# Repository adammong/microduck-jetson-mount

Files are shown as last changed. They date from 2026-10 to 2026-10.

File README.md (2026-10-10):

# MicroDuck Jetson Orin Nano mount

Parametric CAD, printable parts, assembled previews and MuJoCo models for an external MicroDuck compute mount. Current design: **v06**, with the Jetson low in front, ports upward, and a **GNB8504S60AHV 4S LiHV 850 mAh battery** behind the torso to balance it.

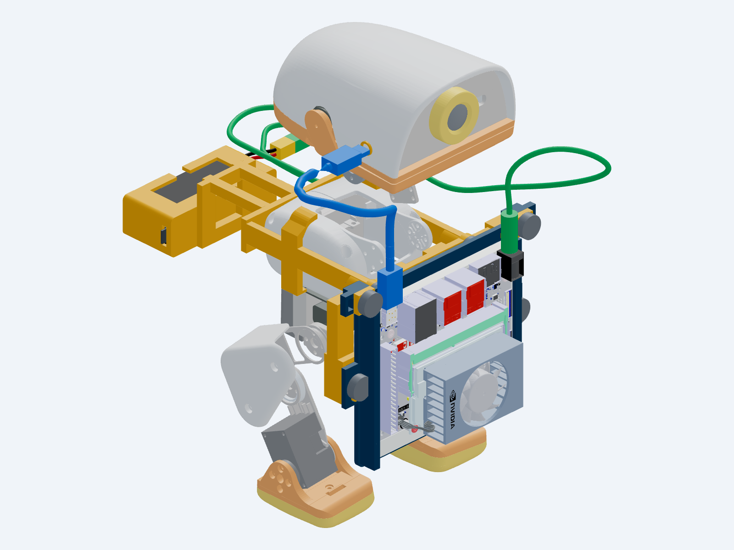
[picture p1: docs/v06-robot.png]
MicroDuck with the balanced v06 mount


## Directional control

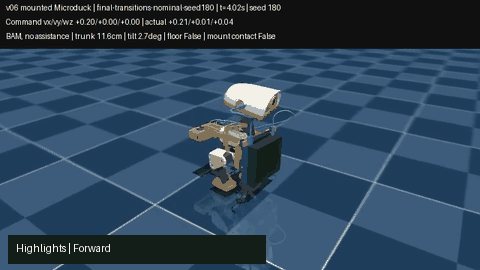
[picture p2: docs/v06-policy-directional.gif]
Directional-control highlights


The new **Mac-calibrated directional policy** supports forward/backward, sidesteps, turns, diagonals and curves. It passed **176/176 fresh 30-second simulation trials** with the v06 payload, including observation noise and randomized physics, plus **8/8 complete 69-second control sequences**, with no detected mount contacts. Direction tracking is checked separately from staying upright. Forward/backward presets are +0.20/-0.15 m/s, sideways ±0.10 m/s and turns ±0.40 rad/s. Low-speed commands can still hit the inherited dead zone; hardware is untested.

**Try it on the Mac:** after [setup](training/README.md), run `OMP_NUM_THREADS=1 tmp/microduck-lab/microduck_local/.venv/bin/python training/teleop_motion.py`, then open http://127.0.0.1:8798. Hold **W/S** forward/back, **A/D** sideways, **Q/E** turn; **Space** stops. Movement and turn keys combine into curves. The control page includes command ramps, stale-command stopping and reset.

[Full directional video](https://github.com/adammong/microduck-jetson-mount/raw/refs/heads/main/results/motion-v06/motion-demo.mp4) · [Selected ONNX](results/motion-v06/policies/selected/policy.onnx) · [Measurements, training and limitations](results/motion-v06/REPORT.md).

## Faster walking video

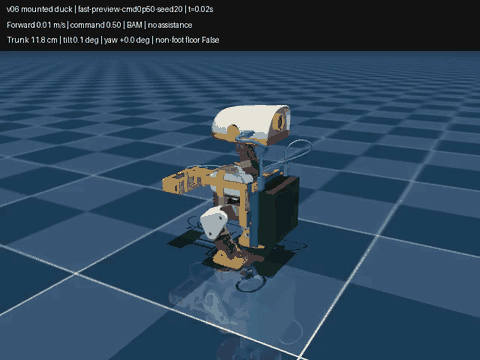
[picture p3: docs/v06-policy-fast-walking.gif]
Faster walking policy on the loaded v06 robot


**New Mac-trained fast-walking policy:** about **0.27 m/s**, roughly **59% faster** than the original policy's successful normal walks. It survived **16/16 fresh 30-second trials**, including observation noise and randomized physics, with no detected mount contacts. Four start/stop sequences also survived. The selected policy retains the original walking network and adds small trained gyro/gravity corrections; both PPO fine-tunes remain rejected.

[Watch the fast-walking MP4](https://github.com/adammong/microduck-jetson-mount/raw/refs/heads/main/results/speed-v06/fast-walking.mp4) · [Selected ONNX policy](results/speed-v06/policies/selected/policy.onnx) · [Measurements, limits and reproduction](results/speed-v06/REPORT.md). Tested forward command: `[0.5, 0, 0]`. This is fast walking in simulation; hardware performance and higher-speed running remain unverified.

Original policy comparison:

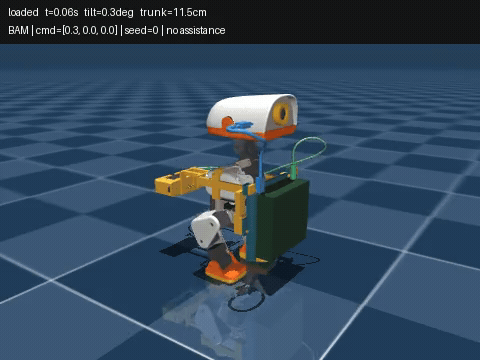
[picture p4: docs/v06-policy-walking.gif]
Walking policy on the loaded v06 robot


[Watch or download the full MP4](https://github.com/adammong/microduck-jetson-mount/raw/refs/heads/main/results/mac-v06/preview-loaded-forward.mp4). This is the unchanged official walking policy on the loaded v06 model in Mac MuJoCo simulation, with no assistance; it is not a hardware demonstration. The earlier PPO fine-tunes remain rejected.

## Start here

- [Assembly, hardware, printing and limitations](easy_mount/README.md)
- [Wiring and compute-board access](easy_mount/WIRING.md)
- [Battery selection and runtime assumptions](easy_mount/battery_selection.json)
- [Complete robot preview](easy_mount/GLB/microduck_easy_mount_v06.glb)
- [Editable CAD assembly](easy_mount/STEP/easy_mount_assembly.step)
- [Five print STLs](easy_mount/STL/)
- [MuJoCo models and validation reports](easy_mount/simulation/)
- [Mac simulation and training](training/README.md) · [Faster walking results](results/speed-v06/REPORT.md) · [v06 simulation findings](results/mac-v06/REPORT.md) · [historical v05 findings](results/mac-v05/REPORT.md)

The estimated payload is **442.1 g**, including **120.1 g** fully dense PETG and estimated ancillary hardware. The battery is specified at **73 g**, with **12.92 Wh** nominal energy. Runtime arithmetic estimates 22–37 minutes at 15–25 W total Jetson draw, including reserve and conversion losses; it does not predict robot motor runtime.

## Prototype status

Physical shell fit, structural strength, power conditioning/protection and hardware walking are unverified. The directional policy now follows the measured motion presets in the loaded simulation; arbitrary slow speeds remain ineffective. The original teacher and rejected candidates remain available for comparison. Full joint travel has recorded collisions. The blue USB cable ends at a free, unverified head-side plug; the amber ring is a survey marker, not a stock port. Approximate purchased leads/connectors are illustrated. The larger 1100 mAh pack was researched but has **not** been integrated into this CAD.

## Rebuild

Use Python 3.12. From the repository root:

```sh
python3.12 -m venv .venv
.venv/bin/python -m pip install -r requirements.txt
sh easy_mount/build.sh
.venv/bin/python checks/package_easy_mount.py
```

Only print the five files in `easy_mount/STL/`. Electronics, battery, wires, knobs and straps are purchased components. CAD dimensions are millimeters; MuJoCo uses meters and kilograms.

See [third-party attribution](THIRD_PARTY.md). Upstream robot assets and NVIDIA geometry retain their respective terms.

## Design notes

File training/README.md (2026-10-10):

# Local Mac simulation and training

Uses [MicroDuck Lab](https://github.com/jonathanhawkins/microduck-lab/tree/bbf0326ef97975f7062368914e0729504d17226f), pinned to `bbf0326ef97975f7062368914e0729504d17226f`. Native CPU MuJoCo and PPO work on Apple Silicon; CUDA is unnecessary for these experiments.

The current CAD revision is the source of payload mass, inertia and collision boxes. Stock and loaded scenes share the robot, floor, STAND keyframe, BAM XL330 motor model, 200 Hz physics and 50 Hz policy interface: **61 observations / 14 actions**. Both use the fuller groundcontact robot. The Jetson visual is an envelope; cables are fixed and the mount cannot slip or break in this model.

## Run

From the repository root, with [uv](https://docs.astral.sh/uv/getting-started/installation/) installed:

```sh
uv run --python 3.12 training/setup_mac.py
tmp/microduck-lab/microduck_local/.venv/bin/python training/verify.py
tmp/microduck-lab/microduck_local/.venv/bin/python training/evaluate.py --strict --seeds 8 --seconds 20 --render
tmp/microduck-lab/microduck_local/.venv/bin/python training/evaluate.py --variant loaded --strict --extended --bus-delay --obs-noise
```

Outputs use the revision in `easy_mount/parameters.json`: current metrics/videos go into `results/mac-v06/`, and compiled scenes into `tmp/mac-models/v06/`. `--revision v05` evaluates preserved local v05 scenes if present; a fresh checkout must build those from the historical CAD revision first. Existing historical results are committed in `results/mac-v05/`.

## Exact teacher import and bounded fine-tuning

The official ONNX actor can now be copied exactly into a resumable PPO checkpoint. Its normalizer and ELU layers are retained; only the initial critic is fitted to mounted rollouts. Equality is asserted before and after critic fitting. This avoids approximate actor cloning and preserves normalized command slots during later warm starts.

```sh
tmp/microduck-lab/microduck_local/.venv/bin/python training/import_teacher.py --episodes 80 --critic-epochs 20
tmp/microduck-lab/microduck_local/.venv/bin/python training/train_pair.py --variant loaded --steps 262144 --init-from tmp/mac-runs/v06-teacher-import-s0 --lr 0.00001 --run-tag teacher
tmp/microduck-lab/microduck_local/.venv/bin/python training/verify_teacher.py --warm-run tmp/mac-runs/v06-loaded-bam-s0-262144-strict-warm-teacher
```

The training driver runs bounded paired numerical studies with eight workers, CPU PPO and a strict floor-support guard. It uses nominal mass and no observation noise; BAM still samples startup voltage/sag and uses bus delay. This is not the full hardware-transfer recipe. Use the upstream live LAB for general skill training. Logs, checkpoints and exports are stored in `tmp/mac-runs/`. `--seed`, `--run-tag`, `--lr` and `--init-from` control repeat studies. Existing outputs are preserved; choose a fresh run tag to repeat. Archived checkpoints use `model.sb3`; the driver restores this native ZIP container to temporary `model.zip` before loading it.

The guard ends an episode after three successive control steps with a non-foot floor contact carrying more than 0.05 N. Observations, actions, rewards and motor limits remain intact. `--allow-nonfoot-support` exists only to reproduce the historical backpack-supported failure. Evaluation defaults to nominal physics, with optional communication delay, observation noise and domain randomization. Trials load isolated model copies and seed both construction and reset.

## Results and selection

The [directional-motion study](../results/motion-v06/REPORT.md) adds a simulation controller for forward/backward, both sidesteps, both turns, diagonals and curves, plus a keyboard/button page. Six command-conditioned maps and bounded gyro/gravity corrections retain the teacher's exact neural weights and normalization. Paired CEM studies also calibrate turn startup from settled standing and a gyro-based start boost. Final checks use the same command slew as the page: 176/176 fresh 30-second nominal/randomized trials and 8/8 full 69-second sequences, with separate direction-tracking checks and no detected mount contact. Low-command dead zones and hardware transfer remain unresolved.

```sh
OMP_NUM_THREADS=1 tmp/microduck-lab/microduck_local/.venv/bin/python training/teleop_motion.py
OMP_NUM_THREADS=1 tmp/microduck-lab/microduck_local/.venv/bin/python training/verify_motion.py
OMP_NUM_THREADS=1 tmp/microduck-lab/microduck_local/.venv/bin/python training/evaluate_motion_batch.py --policy results/motion-v06/policies/selected/policy.onnx --out tmp/directional.json --seeds 8 --seed-start 200 --seconds 30 --slew
```

Open http://127.0.0.1:8798. W/S forward/back, A/D sideways, Q/E turn, Space stop. Body-frame presets are +0.20/-0.15 m/s forward/back, ±0.10 m/s sideways and ±0.40 rad/s yaw; movement/turn keys combine. The controller requires its tested command ramp and 0.6-second stale-input watchdog. It exports one 61-input/14-output ONNX; CEM parameters and all searches are retained. This is a bounded numerical calibration study, rather than another PPO fine-tune. Earlier candidates, cold-start failures and missed turns remain in the report.

The [faster-walking study](../results/speed-v06/REPORT.md) selects a **simulation-only** feedback correction policy for forward command `[0.5, 0, 0]`. It averages 0.266 m/s net forward progress, with 16/16 fresh 30-second nominal/randomized trials surviving without detected mount contacts. The original teacher network and normalization are retained; bounded gyro/gravity corrections are trained with CEM. Normal/idle commands at or below 0.35 retain the original teacher's output exactly. The study records the rejected 2M/3M-step LAB PPO attempts and the complete bounded calibration history.

```sh
OMP_NUM_THREADS=1 VECLIB_MAXIMUM_THREADS=1 tmp/microduck-lab/microduck_local/.venv/bin/python training/tune_fast_feedback.py --out tmp/repeat-fast-feedback --generations 8 --population 20 --command .5 --seconds 25 --training-seeds 0 1 2 3 4 5 6 7 8 9 10 11
OMP_NUM_THREADS=1 tmp/microduck-lab/microduck_local/.venv/bin/python training/evaluate_speed.py --policy results/speed-v06/policies/selected/policy.onnx --out tmp/recheck-fast.json --commands .5 --seeds 8 --seed-start 20 --seconds 30 --render
```

The selected graph still uses 61 observations / 14 actions at 50 Hz. It is an ONNX policy, with parameters and provenance under `results/speed-v06/policies/selected/`; it is not a resumable PPO checkpoint. CEM resumes conceptually from its recorded parameters/search, and PPO comparison checkpoints remain separately archived. Published measurements validate the 0.5 forward operating point, not higher speeds or general turning. See the report for sampling limits and hardware gaps.

[The v06 report](../results/mac-v06/REPORT.md) shows a substantial **mount balance improvement** with the unchanged walking teacher. The teacher remains the preferred comparison actor: both fine-tuning attempts failed to beat it reliably. Their checkpoints are marked rejected. Surviving a reverse, lateral or turn-in-place trial does not mean following its command; these motions remain ineffective. Randomized forward/curved trials still expose falls and occasional mount contacts.

The [v05 pilots](../results/mac-v05/REPORT.md) are also rejected. Retained artifacts support reproducibility, not deployment. Printed mass, motor heating, shell strength and real fit remain unverified. Inputs and checksums are in [inputs.json](inputs.json); scene source hashes in [scenes.json](../results/mac-v06/scenes.json). The pinned harness's `uv.lock` fixes training dependencies; CAD dependencies remain separate.

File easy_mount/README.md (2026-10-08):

# External captive Jetson mount — v06 fit prototype

The Jetson Orin Nano developer kit sits **low in front**, with USB/Ethernet/DC ports upward. The GNB 4S 850 mAh battery sits **behind the torso**, counterbalancing the Jetson. Two independent corner retainers replace the head-interfering crossbar. Tray windows reduce plastic mass. The external torso capture remains; mounting does not require opening the torso or removing its screws.

## Attach the mount and Jetson

1. Prepare the five prints below, insert six M4 nuts, and fit nonconductive foam: nominally 1 mm at the upper saddle seats and 2 mm at the torso gate pads. Clear supports and tune nut-pocket clearance to the printer.
2. Support the powered-off duck. Remove the yellow front torso gate. Slide the saddle forward onto the torso from behind: upper seats rest on the shell shoulders; lower lips capture its side undersides. Refit the gate with **two M4×20 thumb screws**, seated gently.
3. On the bench, remove the tray's **two small corner retainers**. Keep NVIDIA's white plastic base attached. Orient its connector edge upward and slide the base down between the rails to the lower stops. Refit the retainers with **two M4×12 thumb screws**. These retain the plastic base; no PCB holes are used.
4. Engage the tray's locating holes on the front gate's outboard pins. Secure **two M4×20 thumb screws**. Removing these two screws releases the equipped tray later.
5. Place the battery on the 0.6 mm bottom pad in the rear pocket, then strap it through the pocket slots. Its leads leave through the short-edge notch. Strap a verified power-conditioning/protection device to the rear side pad. Restrain wiring with slack at moving joints.

These are intended operations, not a physically demonstrated installation. Production shell fit, pad compression and fastener access need a fit print. Connecting the duck's compute board may require separate head access. The amber ring is a survey marker, **not a stock port**; the blue head-end plug is deliberately disconnected. See [WIRING.md](WIRING.md).

## Parts and printing

Print only these five files:

- `STL/saddle.stl`
- `STL/front_gate.stl`
- `STL/jetson_tray.stl`
- `STL/jetson_gate_left.stl`
- `STL/jetson_gate_right.stl`

Hardware: four M4×20 and two M4×12 thumb screws; six ISO 4032 M4 nuts; nonconductive pads and retaining straps. Electronics, cables, battery, converter and gray knobs are purchased-component illustrations.

Screw holes are 4.5 mm; nut pockets are 7.25 mm across flats and 3.5 mm deep. The OEM base is nominally 103×90.5 mm. The rail internal width is 104.2 mm, with 0.8 mm lip overlap and nominal 0.5 mm clearance above the base. PETG is the mass assumption; capture seats, rail lips, ears and nut pockets still require support and strength review. All print STLs are watertight, with their bottom at Z=0. No slicer or strength certification is implied.

Battery: **GNB8504S60AHV**, 73×18×32 mm, 73 g ±2 g, 15.2 V, 850 mAh, 12.92 Wh. Body center `[-122.6,0,0]` mm in trunk coordinates. Pocket interior 75×20 mm, 36 mm deep. End straps occupy the nominal 1 mm end clearance; tune their thickness to the actual pack. Factory lead placement and XT30/balance connectors are approximate. The converter remains an **unselected** 14×24×12 mm allowance.

## CAD and simulation

- [Complete robot preview](GLB/microduck_easy_mount_v06.glb)
- [Equipped mount](GLB/equipped_mount_v06.glb)
- [Head wiring inspection](GLB/head_wiring_inspection_v06.glb): older reference PCB footprint, with the cover omitted; production Radxa socket geometry is unverified.
- [Editable assembly](STEP/easy_mount_assembly.step), plus five individual print STEP files.
- `simulation/microduck_easy_mount_{walk,groundcontact}.xml`: both baseline robot variants, with explicit payload inertia, zero-mass visuals and active rigid mount collision boxes.
- `simulation/{mass_properties,validation,balance_estimate}.json`: generated numerical results.
- [Mac simulation report](../results/mac-v06/REPORT.md).

CAD units are millimeters; simulation uses meters and kilograms. Trunk X is forward, Y left, Z up. Tray local `(X,Y,Z)` maps to trunk `(Z,X,Y)` plus `[50,0,-18]` mm; the vendor kit rotates 180° around tray Z first. `parameters.json` controls positions, dimensions and mass assumptions.

Payload mass is **442.1 g**: **120.1 g** fully dense PETG, Jetson 175 g, battery 73 g, and 74 g ancillary allowance (fasteners/pads/straps 22 g, data cable 14 g, power wiring/extension 18 g, conditioning/protection 20 g). The payload is counted once; the stock robot battery remains. Weigh sliced prints and purchased hardware before calibrating inertia. Cable mass is fixed in HOME; head articulation and cable tension are not modeled.

## Verification and limits

Five valid single print solids and five watertight STLs pass native print/print, battery/strap/factory-lead/print and wire/print intersection checks. The 50 mm upward plug corridor clears prints and the sampled robot poses. HOME plus 126 individual-joint samples within ±0.2 rad has no reported penetration beyond 0.2 mm. **Full-range motion still records 140 interfering pairs**; this design does not clear the complete stock motion range or combined head/leg motions.

Static HOME COM shifts **2.1 mm forward, 1.5 mm left and 9.0 mm down**. Optimistic rear sole margin is **22.7 mm**, versus 8.5 mm in v05 and 20.5 mm stock. This assumes usable contact over the entire projected sole; it is not a payload rating. Paired walking rollouts support the balance improvement, but hardware strength, fit, motor temperature and power remain unverified.

## Battery and power

[Manufacturer specification](https://www.gaoneng.shop/products/gaoneng-gnb-lihv-4s-15.2v-850mah-60c-xt30-lipo-battery-long-range) and [selection record](battery_selection.json) document the pack. No exact battery CAD was available: its body uses published dimensions, with illustrative leads and connectors.

At 15–25 W total Jetson draw, 80% usable energy and 90% conditioning efficiency imply **22–37 minutes**. This does not predict robot motor runtime. Full-charge 17.4 V is within NVIDIA's published 9–20 V carrier input range, but protection, transients, cutoff and the actual circuit are unvalidated. Use suitable LiHV charging equipment and verify actual lead exit, plugs and power hardware before fitting.

## Rebuild

From the repository root, using the Python 3.12 CAD environment:

```sh
sh easy_mount/build.sh
.venv/bin/python checks/package_easy_mount.py
```

`CAD_PYTHON` can select an existing CAD interpreter. Model sources are in `src/`, shared geometry in `src/lib/`, checks in `checks/`. The packaging command creates a versioned ZIP under `dist/` containing the current design and pinned rebuild inputs. See [third-party attribution](../THIRD_PARTY.md); robot and NVIDIA assets retain their respective terms.

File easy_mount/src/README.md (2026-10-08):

# Model catalog

Four scripts build print parts with STEP/STL/GLB outputs of the same name.
The wiring and purchased battery models have STEP/GLB only because it represents purchased components.
The assembly calls the four child models and restores their manufacturing poses.

| Script | Purpose |
| --- | --- |
| saddle.py | External torso capture and tray support/docking |
| front_gate.py | Two-screw removable torso closure and forward battery cradle |
| jetson_tray.py | OEM-base capture rails, corner support tabs and open connector edge |
| jetson_gate.py | Open U gate retaining the OEM base; bridge below head |
| wiring_layout.py | Approximate USB/power cables and unselected converter envelope |
| battery_pack.py | GNB8504S60AHV specified body and approximate stock leads, connectors and strap |
| easy_mount_assembly.py | Installed mechanism, purchased screws, battery and wiring envelopes |

Factory geometry, print transforms and assembly transforms are in `lib/design.py`.

Cable routing and plug assumptions are in `lib/wiring.py` and `../WIRING.md`.

Battery geometry is in `lib/battery.py`; source specifications and inertia assumptions are in `../battery_selection.json`.

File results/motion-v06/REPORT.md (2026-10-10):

# Directional motion with the v06 Jetson mount

Directional-control highlights

**Selected simulation policy:** [policy.onnx](policies/selected/policy.onnx). It moves forward, backward and sideways, turns in both directions, follows curves and stops. It retains the official walking network and learns command mapping and bounded IMU feedback. **176/176** fresh 30-second trials survived without detected mount contact or non-foot floor support. **8/8** complete 69-second control sequences also survived and followed every requested direction.

[Full continuous video](motion-demo.mp4) · [second seed](final-transitions-nominal-seed181.mp4) · [frame sheet 180](final-transitions-nominal-seed180.png) · [frame sheet 181](final-transitions-nominal-seed181.png) · [selection](selection.json)

## Control it on the Mac

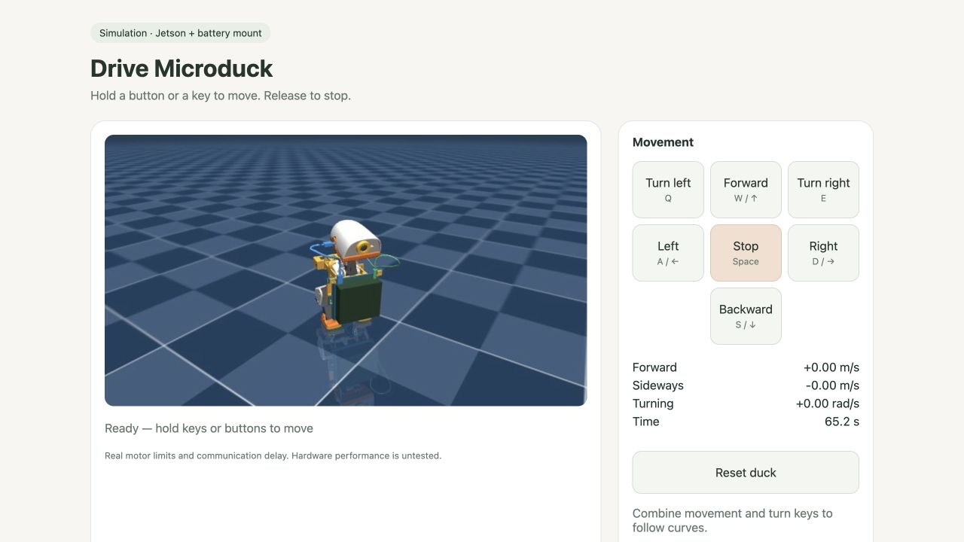
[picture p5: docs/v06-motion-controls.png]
Mac motion controls


After [setup](../../training/README.md), run from the repository root:

```sh
OMP_NUM_THREADS=1 tmp/microduck-lab/microduck_local/.venv/bin/python training/teleop_motion.py
```

Open http://127.0.0.1:8798. Hold **W/S** for forward/backward, **A/D** for left/right, **Q/E** to turn. Arrow keys also translate. **Space** stops immediately; releasing keys ramps to a stop. Movement and turn keys combine into curves. Buttons work with mouse/touch. Reset returns to standing; a fall pauses the simulation. The server binds only to this Mac and exits after 15 minutes without input activity.

The command is body-frame `[vx m/s, vy m/s, wz rad/s]`: forward follows the duck's current heading. These controls use tested presets: +0.20/-0.15 m/s forward/backward, ±0.10 m/s sideways, ±0.40 rad/s turning. Translation/yaw acceleration limits are `[0.5, 0.3, 1.5]` in the corresponding units per second. A 0.6-second stale-command watchdog requests a stop. [Limiter](../../training/motion_controller.py) and [interactive simulation](../../training/teleop_motion.py) share the path used by the transition checks.

**Low-speed limitation:** this is a directional prototype at the measured speeds, not accurate continuous speed control. Commands at half the presets can remain in the inherited network's standstill dead zone. Arbitrary joystick magnitudes, all three axes together, disturbances and terrain are not validated. The earlier faster straight-walk policy remains available separately; this controller prioritizes direction control.

## Measurements

Tuple columns are signed body-frame **vx, vy, wz**; linear speeds use m/s and turn rates rad/s. Values average samples after the first two seconds, through the same production command ramp as the control page, without a world-heading hold. Nominal confirmations use fresh seeds **200–207** and noise/randomization confirmations use **220–227**. Calibration used only **0–7**. Every active requested axis delivers at least half its requested signed speed/rate in each individual confirmation trial; survival is checked separately from following a command.

| Motion | Requested twist | Nominal actual twist | Noise + randomized physics actual | Survived 30 s |
|---|---|---|---|---:|
| stop | [0.0, 0.0, 0.0] | +0.000, +0.000, +0.001 | -0.000, -0.000, +0.000 | 16/16 |
| forward | [0.2, 0.0, 0.0] | +0.209, -0.002, -0.006 | +0.207, -0.002, -0.013 | 16/16 |
| backward | [-0.15, 0.0, 0.0] | -0.165, -0.004, -0.005 | -0.159, -0.004, -0.004 | 16/16 |
| left | [0.0, 0.1, 0.0] | -0.001, +0.097, +0.005 | -0.000, +0.095, +0.017 | 16/16 |
| right | [0.0, -0.1, 0.0] | -0.005, -0.099, +0.000 | -0.003, -0.099, +0.001 | 16/16 |
| turn left | [0.0, 0.0, 0.4] | -0.004, -0.003, +0.464 | -0.003, -0.003, +0.470 | 16/16 |
| turn right | [0.0, 0.0, -0.4] | +0.003, -0.002, -0.415 | +0.004, -0.002, -0.414 | 16/16 |
| curve left | [0.15, 0.0, 0.3] | +0.130, +0.004, +0.393 | +0.128, +0.003, +0.386 | 16/16 |
| curve right | [0.15, 0.0, -0.3] | +0.136, -0.003, -0.329 | +0.133, -0.002, -0.329 | 16/16 |
| diagonal left | [0.15, 0.07, 0.0] | +0.132, +0.078, +0.048 | +0.129, +0.077, +0.036 | 16/16 |
| diagonal right | [0.15, -0.07, 0.0] | +0.132, -0.063, +0.017 | +0.127, -0.063, +0.028 | 16/16 |

Full keyboard forward/back + turn combinations also passed **16/16** separate 20-second trials without detected contacts: [keyboard curve checks](keyboard-curves.json).

[Nominal results](final-confirmation-nominal.json) · [Noise + DR results](final-confirmation-noise-dr.json). Randomization uses the pinned harness's mass/inertia/CoM/armature/friction and motor voltage/sag treatment; external pushes stay disabled. The scene's nominal total mass is **1.179337 kg**, including the estimated **442.094 g** mount/Jetson/battery/cable payload. Physics runs at 200 Hz, ONNX at 50 Hz, with honest BAM XL330 limits (1.75 A) and 15–30 ms bus lag. No stronger motors, assistance or floor-support cheat.

The control sequences include stop → forward → stop → backward → sidesteps → turn → walk along the new heading → reverse turn → curves → stop. Nominal seeds **180–183**, randomized seeds **240–243**, all 69 seconds with the same command slew as the page. Each active axis also passes the half-requested-speed direction check in every sequence segment after the initial one-second transition. The largest mean residual translation during a stop segment was **0.0013 m/s**. [Nominal sequences](final-transitions-nominal.json) · [randomized sequences](final-transitions-noise-dr.json). Minimum sampled torso height across confirmations and sequences was **10.8 cm**; both rendered frame sheets were inspected.

## What was learned

Six command-conditioned profiles map the requested twist into a useful gait range of the pinned `alpha_walking.onnx`, then add bounded static/gyro/gravity joint corrections. Profiles blend for combined commands. The yaw input also uses the observed gyro yaw-rate error; absolute world yaw/position and privileged velocity are not actor inputs. Joint corrections are clipped to ±0.12 rad (6.9°). A zero twist reproduces the teacher exactly. The teacher normalizer and neural weights are unchanged, and the final 61-input / 14-output ONNX contains the command map and all feedback, including its simulation-only provenance.

Initial CEM: six profiles × eight generations × 20 candidates, four paired seeds, 12-second trials. Turn refinement: two profiles × 12 generations × 24 candidates, eight paired seeds, 20-second trials. The second candidate passed all 176 constant-command tests but could stall on turns after settling into standing; its policy, transition video and metrics remain **not selected** under `policies/turn-fit` and the initial result filenames. A final turn study trains the same body-twist objective from four seconds of standing, through the production command ramp: two profiles × eight generations × 24 candidates, eight paired seeds, 16-second trials. That settled-start candidate still missed one randomized transition turn and fell in one abrupt-start forward test (175/176 survival). The production ramp prevents that forward failure. Finally, a five-value paired grid calibrates a gyro-based pure-turn start boost on 16 full nominal/randomized control sequences per value; 0.30 is selected with no missed turns in training. This adds yaw-command boost only while the observed gyro is low, using no clock or hidden state. No PPO update or physics strength change is involved.

Searches: [initial](calibration/search.json), [turn fit](turn-refinement/search.json), [settled-start refinement](transition-refinement/search.json), [turn-activation grid](activation-study/search.json). Each retains full candidates, seeded trials and an executed source snapshot. [Selected parameters](policies/selected/parameters.json) · [run manifest](policies/selected/run.json) · [export/physics/watchdog verification](final-verification.json). The verifier compares 1,000 fresh inputs with the numerical policy, checks unchanged teacher tensors/normalization, exact stop behavior, correction bounds, command limits, finite inputs, watchdog stop and unassisted null-control falls.

## Limits and reproduction

These finite tests establish the measured directions in this approximate loaded model. Hardware walking, mount flex/slip, cable forces, motor temperature, battery discharge, terrain and full joint-clearance coverage remain unverified. Contact statistics count forces above 0.05 N at 50 Hz; substep impacts can be missed. The existing full-range CAD collision findings still apply. Abrupt raw-command startup is outside the selected control path: [the retained settled candidate](settled-confirmation-nominal.json) fell on one nominal forward start; [the ramp check](startup-ramp-check.json) reproduced that seed successfully with the production limiter. Both this ramp and the turn-start activation belong to the tested controller. This is fast local prototyping, not hardware-transfer validation. The GIF is a clearly cut highlights reel; the linked MP4 is a continuous rollout at normal simulated time.

```sh
OMP_NUM_THREADS=1 tmp/microduck-lab/microduck_local/.venv/bin/python training/verify_motion.py
OMP_NUM_THREADS=1 tmp/microduck-lab/microduck_local/.venv/bin/python training/evaluate_motion_batch.py --policy results/motion-v06/policies/selected/policy.onnx --out tmp/motion-nominal.json --seeds 8 --seed-start 200 --seconds 30 --slew
OMP_NUM_THREADS=1 tmp/microduck-lab/microduck_local/.venv/bin/python training/evaluate_motion_batch.py --policy results/motion-v06/policies/selected/policy.onnx --out tmp/motion-dr.json --seeds 8 --seed-start 220 --seconds 30 --noise-dr --slew
OMP_NUM_THREADS=1 tmp/microduck-lab/microduck_local/.venv/bin/python training/evaluate_transitions.py --policy results/motion-v06/policies/selected/policy.onnx --out tmp/motion-sequence.json --seeds 4 --seed-start 180 --render
```

For complete recalibration, run `training/tune_motion.py --out tmp/motion-initial`, then `training/tune_motion.py --out tmp/motion-turns --generations 12 --population 24 --seconds 20 --seeds 0 1 2 3 4 5 6 7 --modes turn_left turn_right --init tmp/motion-initial/candidate/parameters.json`, then `training/refine_motion_transitions.py --out tmp/motion-settled --init tmp/motion-turns/candidate/parameters.json`. Then run `training/tune_motion_activation.py --out tmp/motion-activation --init tmp/motion-settled/candidate/parameters.json`. Keep the recorded seeds/defaults and the pinned Mac setup. Attribution: [LICENSE](policies/LICENSE), [NOTICE](policies/NOTICE).

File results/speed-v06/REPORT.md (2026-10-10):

# Faster walking with the v06 Jetson mount

**Selected simulation policy:** [policy.onnx](policies/selected/policy.onnx), forward command `[0.5, 0, 0]`. It covers **0.266 m/s** along the original forward line and averages **0.269 m/s** in the body frame. All **16/16** fresh nominal/randomized forward trials lasted 30 seconds with no detected payload contact or non-foot floor support. The separate start/stop sequence passed **4/4** trials.

Faster walking

[Full video](fast-walking.mp4) · [second seed](fast-preview-cmd0p50-seed21.mp4) · [frame sheet 20](fast-preview-cmd0p50-seed20.png) · [frame sheet 21](fast-preview-cmd0p50-seed21.png) · [selection metrics](selection.json)

## Measured comparison

Same v06 loaded scene, estimated 1.179337 kg robot total / 442.094 g payload, 200 Hz physics, 50 Hz deterministic ONNX actions, BAM XL330 model with 1.75 A current limit and 15–30 ms command-bus lag. No stronger servos or assist forces. All table trials start from STAND with a fixed forward command, zero head/body commands and fresh seeded models.

| Policy / condition | Command m/s | Survived 30 s | Body forward m/s | Net world-forward m/s | Mean absolute yaw drift | Largest payload-contact time fraction |
|---|---:|---:|---:|---:|---:|---:|
| Teacher: normal walk | 0.30 | 7/8 | 0.159 | 0.147 | 18.2 | 26.5% |
| Teacher: larger command | 0.50 | 8/8 | 0.249 | 0.083 | 124.0 | 0.0% |
| Selected feedback: nominal | 0.50 | 8/8 | 0.269 | 0.266 | 14.1 | 0.0% |
| Selected feedback: noise + DR | 0.50 | 8/8 | 0.276 | 0.271 | 17.3 | 0.0% |

Nominal confirmation uses **seeds 20–27**, which were absent from calibration. Randomized confirmation uses **seeds 40–47**, with observation noise, bus delay and the harness's domain randomization enabled. Results: [teacher](teacher-confirmation-nominal.json), [feedback nominal](feedback-confirmation-nominal.json), [feedback randomized](feedback-confirmation-noise-dr.json). Each aggregate includes all eight trials, including the teacher's early fall. Its seven successful normal-walk trials averaged 0.167 m/s net travel; selected fast walking is **59.1% faster** than that successful-walk average. The larger teacher command alone mostly produces arcs, which is why both body velocity and ground covered are reported.

Randomized trials keep external push disturbances disabled. All four transition trials also returned to effectively zero forward speed during the final second of each stop phase (less than 0.001 m/s in magnitude).

This is **fast walking**. Both-feet-airborne samples occupy about 0.08% of the nominal rollouts; this experiment does not establish a sustained running gait.

## What was trained

Two LAB-launched PPO warm starts ran locally on the Mac: 2,007,040 steps with the original running scorecard, then 3,006,464 steps with stronger speed/gyro-yaw tracking and reduced airtime reward. The second donor's critic was fitted separately to 80 mounted episodes, and its deterministic actor was verified unchanged. Both PPO policies lost net forward progress to circling and remain **rejected**, with resumable checkpoints, normalizers, recipe snapshots, logs and comparisons under [policies](policies/). [Rejected PPO footage](rejected-ppo-preview-cmd0p55-seed0.mp4) shows the turn accumulating despite survival.

Bounded CEM numerical studies then calibrated corrections around the exact original actor. Static offsets improved short trials but failed longer/fresh-seed checks; a 0.75 command produced right-foot/tray contacts. The selected study uses **11 parameters**: six constant joint corrections plus five gains on observable gyro/gravity signals. It optimizes body forward speed and mean gyro yaw rate, rejects falls/non-foot support/payload contacts, penalizes contact time and regularizes correction size. It uses no absolute world-heading input, hidden velocity observation, force assistance or torque-limit change.

Calibration: eight generations × 20 candidates, paired **seeds 0–11**, 25-second trials at command 0.5, fixed reward/fitness throughout. See [complete search](feedback-study/search.json), [source snapshot](feedback-study/tune_snapshot.py) and [selected parameters](policies/selected/parameters.json). The original 61-input / 14-output MLP and its normalization are retained. Added joint corrections are clipped to ±0.08 rad (4.6°). They ramp with raw forward command from 0.35 to 0.45 and are exactly zero for command ≤0.35, including stand, reverse and ordinary 0.3 walking. Other motion commands have not been validated with the fast correction active.

ONNX and numerical-wrapper output agree exactly on the test inputs. The untouched normal/idle path also agrees exactly with the original teacher. The selected ONNX includes its standard 61/14 contract and a simulation-only status. [Verification](feedback-verification.json) includes 1,000 fresh input checks and four 30-second stand → fast → stop → normal → fast → stop sequences (seeds 60–63).

## Scope

These are finite simulation checks, not a hardware-ready controller. Forward command 0.5 is the tested fast operating point; higher commands, turning, uneven terrain and long battery-discharge runs are unvalidated. Contact statistics are sampled at 50 Hz and count forces above 0.05 N; substep impacts can be missed. No detected contacts in these trials do not establish full joint-clearance coverage. Full-range v06 collision findings remain in the mechanical report.

Estimated masses, rigid attachment, fixed cables, approximate payload collision boxes and BAM motor dynamics remain the model's assumptions. Mount flex/slip, lead forces, motor temperature and real print fit are not simulated. The video is a deterministic unassisted MuJoCo rollout on the Mac, at normal simulated time; no heading-hold controller is added for filming.

## Reproduce

After [Mac setup](../../training/README.md), run from the repository root:

```sh
OMP_NUM_THREADS=1 VECLIB_MAXIMUM_THREADS=1 tmp/microduck-lab/microduck_local/.venv/bin/python training/tune_fast_feedback.py --out tmp/repeat-fast-feedback --generations 8 --population 20 --command .5 --seconds 25 --training-seeds 0 1 2 3 4 5 6 7 8 9 10 11
OMP_NUM_THREADS=1 tmp/microduck-lab/microduck_local/.venv/bin/python training/evaluate_speed.py --policy results/speed-v06/policies/selected/policy.onnx --out tmp/recheck-fast.json --commands .5 --seeds 8 --seed-start 20 --seconds 30
OMP_NUM_THREADS=1 tmp/microduck-lab/microduck_local/.venv/bin/python training/evaluate_speed.py --policy results/speed-v06/policies/selected/policy.onnx --out tmp/recheck-fast-dr.json --commands .5 --seeds 8 --seed-start 40 --seconds 30 --obs-noise --domain-rand
```

Pinned inputs and software are in [training inputs](../../training/inputs.json) and the Mac training README. Policy attribution and licensing are in [LICENSE](policies/LICENSE) and [NOTICE](policies/NOTICE).

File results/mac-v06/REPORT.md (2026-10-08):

# v06 Mac simulation report

**The mount redesign substantially improves nominal balance and forward walking with the unchanged official actor. Neither PPO fine-tuning attempt is selected. This is a fit/simulation prototype, not a hardware-ready walking system.**

## What changed

The Jetson moves low in front of the torso, with the connector edge upward; the 73 g battery moves behind it. Separate corner retainers replace the bar that touched the head. The tray has larger weight-saving windows, and wiring follows the new positions. The two-screw torso capture and two-screw removable equipped tray remain. Five print parts replace the old four; obsolete top-gate print files were removed.

CAD validation reports five valid single solids and watertight STLs, no native print/print, battery/print or wire/print overlaps, and a clear 50 mm plug-access corridor at sampled poses. All five print snapshots and the equipped/full-robot previews were rendered and reviewed. No head bar remains, and ports are visibly upward and accessible in the reference pose.

Payload estimate falls from **451.3 to 442.1 g**; fully dense PETG falls from **129.3 to 120.1 g**. Loaded reference mass is **1.1793 kg**, about 60% above stock. Ancillary hardware is now distributed around its approximate real fastening sites rather than placed in one lump. Mass is estimated, not weighed.

Static HOME COM changes from 12.1 mm behind stock to **2.1 mm ahead**, with a 9.0 mm lower height. Optimistic rear sole margin increases from **8.5 to 22.7 mm** (stock 20.5 mm). These footprint estimates assume contact over the projected sole and do not prove balance.

## Matched CAD comparison

Pinned official `alpha_walking.onnx`, construction/reset seeds 0–7, requested 20 seconds per trial, nominal BAM XL330 motor physics, no assistance, active full groundcontact and mount collision boxes. Strict termination rejects sustained non-foot support. Observation noise and communication delay are off in this first comparison. Commands are zero for standing and +0.30 m/s for forward. Every trial uses a fresh model copy.

| Robot | Stand survival | Mean stand X drift, m | Forward survival | Mean forward X travel, m | Mean forward X speed, m/s |
|---|---:|---:|---:|---:|---:|
| Stock | 8/8 | 0.0016 | 8/8 | 2.059 | 0.103 |
| Loaded v05 | 7/8 | -0.8065 | 8/8 | -0.177 | -0.009 |
| Loaded v06 | 8/8 | 0.0031 | 8/8 | 3.191 | 0.160 |

One v05 standing trial falls early; its endpoint is included in the mean. All v06 nominal standing, forward and turn-command trials survive: **24/24**. Standing and forward trials have zero recorded loaded-payload self contact and zero non-foot ground frames. Forward speed still undershoots the 0.30 m/s command.

**Survival is not task success.** The teacher barely moves on reverse, lateral and pure turning commands. Turn survival in the baseline table must not be described as successful turning. The extended measurements include yaw displacement so this failure is visible.

## Delay, noise and randomized tests

Each suite uses eight seeds, eight commands and 20 seconds: stand, forward, reverse, left/right lateral, left/right pure turns and a forward curve.

- With communication delay and observation noise: teacher **64/64 survives**, mean forward X speed about **0.151 m/s**. One forward trial has a brief mount contact (0.1% of control frames; 0.59 mm maximum penetration), so nominal contact-free results are not a guaranteed clearance envelope.
- With the harness's additional domain randomization: teacher **59/64 survives**, including **6/8 forward** and **7/8 curved** trials. Some falls/contacts remain. This is a diagnostic of the harness's perturbations, not a calibrated payload-mass or motor-temperature robustness study.
- Reverse and lateral speed remains near zero; pure-turn yaw rate remains near zero without domain randomization. The baseline actor does respond to a combined forward/turn command, but it does not reliably cover every requested motion.

Full joint-limit sampling still records **140 interfering pairs**, including large head/leg motions. The narrower HOME ±0.2 rad one-joint sample has no penetration beyond the 0.2 mm reporting threshold; its smallest convex gap is only **0.51 mm**. Combined articulation and flexible cable travel are unvalidated. Do not treat this mount as compatible with the entire stock motion range.

## Exact actor import and CPU fine-tuning

The ONNX normalizer and 512/256/128 ELU actor are copied directly into native PPO. Only the critic is fitted initially, using 40,000 states over 80 mounted teacher episodes. Actor equality is asserted before/after critic fitting: maximum Torch-vs-original action difference **7.2e-7 rad** on collected states. A separate 1,000-state test finds **zero exported ONNX difference**. Warm-start normalizer means and variances, including command slots, remain exactly equal. The 61-observation / 14-action, 50 Hz contract and BAM limits are unchanged.

Two bounded CPU studies use eight workers, nominal geometry/mass, no observation noise during training, bus delay and startup voltage/sag sampling. No symmetry or assistance is used. Both use the strict floor-support guard:

| Actor | Additional PPO steps | Training seed | Learning rate | Training time | Forward survival with delay/noise | Mean forward X speed |
|---|---:|---:|---:|---:|---:|---:|
| Teacher | 0 | — | — | — | 8/8 | 0.151 m/s |
| Short fine-tune | 262,144 | 0 | 1e-5 | 33.8 s | 8/8 | 0.040 m/s |
| Longer fine-tune | 1,048,576 | 1 | 3e-6 | 155.0 s | 7/8 | 0.029 m/s |

Fine-tuned actors veer/turn during a forward command, and fail to improve reverse/lateral/pure-turn behavior. Both are **rejected**. Different training budgets/seeds prevent attributing their difference to learning rate alone. Paired evaluation favors retaining the unchanged teacher as the simulation baseline. Checkpoints are published for reproducibility with explicit status metadata, not deployment approval.

Standing, forward and pure-turn rollouts were recorded and their contact sheets reviewed for both the teacher and the longer fine-tune. The teacher shows alternate foot motion and forward travel; pure turning shows essentially standing. The longer fine-tune visibly turns during a requested straight walk. No spotter or external stabilizer was used.

## Files and reproducibility

- [Baseline](baseline.json), [v05 control](v05-control.json), [comparison summary](comparison.json).
- [Noise/delay](teacher-robustness.json), [domain randomization](teacher-randomized.json).
- [Short fine-tune](finetuned.json), [longer fine-tune](finetuned-long.json).
- [Mass/interface checks](verification.json), [teacher import checks](teacher-import-verification.json), [scene hashes](scenes.json).
- [Checkpoint artifacts and statuses](policies/), [checksums](policy_checksums.json), [training metadata](training_summary.json), [teacher provenance](teacher-provenance.json).
- [Teacher forward video](preview-loaded-forward.mp4), [teacher contact sheet](preview-loaded-forward.png), [rejected fine-tune video](finetuned-preview-loaded-forward.mp4).
- [Setup and commands](../../training/README.md), [CAD validation](../../easy_mount/simulation/validation.json).

Hardware fit, mount stiffness/slip, printed strength, actual mass/inertia, power electronics, flexible cable loads and motor heat remain unmeasured. Training and testing happened on an Apple Silicon M5 Mac using native CPU simulation. The preferred next experiment is a calibrated payload/actuator randomization study and an explicit command-tracking curriculum, after a physical fit check; no hardware test was performed here.

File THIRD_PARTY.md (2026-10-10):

# Third-party assets

## MicroDuck reference robot

Source: https://github.com/pollen-robotics/microduck_rl at commit `273afe0b31c4ab365b9ff806a927b63ac92b5ddd`.

The upstream README states that software is licensed under Apache 2.0, and 3D model files under Creative Commons BY-SA-NC. Preserve upstream attribution and applicable terms; no license version beyond the upstream declaration is inferred here. The original upstream README and software LICENSE are retained in `simulation/reference/`. Per-file source URLs and SHA-256 checksums are in `simulation/reference/provenance.json`. Assembled previews contain these robot model assets.

## NVIDIA developer-kit geometry

Source: NVIDIA Jetson Orin Nano developer-kit 3D STEP download. `GLB/jetson_devkit.glb` is a derived preview of NVIDIA geometry, also included in equipped assembly previews. Original download provenance and checksum are in `STEP/imported/provenance.json`. NVIDIA retains rights to its supplied geometry and applicable download terms; this repository does not grant a new license to those assets.

## Purchased-part illustrations

Battery body dimensions and mass are based on GAONENG GNB specifications linked in `easy_mount/battery_selection.json`. Battery label, lead placement and connectors are simplified illustrations. Standard fasteners, cable overmolds and the power-conditioning allowance are approximate fit geometry, not product manufacturing models. Model sources and documentation distinguish these from the five printable mount parts.

No blanket license is assigned to this mixed-source repository.

The directional-motion policies in `results/motion-v06/` also derive from the pinned Apache-2.0 walking actor. They retain its weights and normalizer and add command maps, bounded gyro/gravity joint feedback and an observable turn-start activation rule. License copies and modification notices accompany the exported policies. Full calibration and selection records distinguish selected simulation artifacts from rejected candidates; hardware performance is unverified.

## Mac simulation and policies

The setup downloads [jonathanhawkins/microduck-lab](https://github.com/jonathanhawkins/microduck-lab) at `bbf0326ef97975f7062368914e0729504d17226f` (Apache 2.0). The simulator scene wrappers are from `pollen-robotics/microduck_rl` at `badc4e7ffe5507fd7acb1a21487bd2925c1afe5a`. The official `alpha_walking.onnx` is downloaded from `pollen-robotics/microduck-policies` revision `088524a64e2557dc453256b6071dbb9d23888802`; it is not redistributed here. Source URLs and SHA-256 hashes are recorded in `training/inputs.json`. The archived stock/loaded pilot policies were trained locally for this study and are marked rejected experimental policies. Source harness and dependency caches stay outside Git.

The v06 native teacher import and fine-tuned derivatives retain that actor's weights. The pinned upstream [model metadata](https://huggingface.co/api/models/pollen-robotics/microduck-policies/revision/088524a64e2557dc453256b6071dbb9d23888802) declares Apache 2.0. Copies of the license and attribution are in `results/mac-v06/policies/LICENSE` and `NOTICE`; modifications and policy selection status are recorded with each artifact. The original downloaded ONNX file remains in the ignored input cache.

The fast-walking study also retains the teacher actor and adds command-gated joint corrections. Its PPO derivatives, numerical studies and selected feedback policy are attributed under `results/speed-v06/policies/LICENSE` and `NOTICE`. The selected policy is validated for the documented simulation cases; hardware performance is unverified.

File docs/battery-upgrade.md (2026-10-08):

# Proposed battery upgrade — not implemented

The current v05 CAD uses GNB8504S60AHV: 4S LiHV, 850 mAh, 73 g, body 73×18×32 mm.

The proposed GNB11004S60AHV is 4S LiHV, 1100 mAh, 88 g ±3 g, body 62×25×33 mm and XT30. Manufacturer source: https://www.gaoneng.shop/products/gaoneng-gnb-lihv-4s-15.2v-1100mah-60c-xt30-lipo-battery-longrange

Nominal energy is 16.72 Wh. With 80% usable energy and 90% conditioning efficiency, estimated Jetson-only runtime is 28.9 minutes at 25 W or 24.1 minutes at 30 W. These are arithmetic estimates, not measured runtime.

Replacing the front battery in the current mass model predicts about 0.96 mm forward COM change and an optimistic rear static sole margin of 9.42 mm versus 8.46 mm for v05. This holds other component masses fixed, omits pocket redesign mass, and checks reference HOME only. More battery weight helps counterbalance the rear Jetson modestly while increasing leg loads.

The pocket, strap, factory lead exits, collision geometry and inertial properties require updating before this pack can be considered part of the design.

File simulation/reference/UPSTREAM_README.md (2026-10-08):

# Microduck RL



RL training environments for [Microduck](https://github.com/pollen-robotics/microduck) —
a ~800 g, ~25 cm tall bipedal robot — built on
[mjlab](https://github.com/mujocolab/mjlab) (MuJoCo Warp) with PPO.
Policies are trained here at 50 Hz, exported to ONNX, and deployed on the real
robot by the runtime in [pollen-robotics/microduck](https://github.com/pollen-robotics/microduck).

<!-- HERO VIDEO — real robot montage: walking, standup, roulade, roller skating.
     Keep it short (~30 s) and real-robot-first: this is the "why should I care" shot. -->

https://github.com/user-attachments/assets/50c3d537-8db2-4005-9d9c-3472faeec4d0

The repo encodes the full sim2real recipe: [BAM](https://github.com/Rhoban/bam)
actuator physics, domain randomization, backlash simulation, and the
reward-design lessons that made it work
(see [AGENTS.md](AGENTS.md) for the distilled playbook).

## Quickstart

Requires a CUDA GPU (training runs through MuJoCo Warp) and [uv](https://docs.astral.sh/uv/).

> **On ARM boxes (DGX Spark / GB10, Jetson):** `uv sync` pulls ~2 GB of CUDA
> wheels on first run and uv's default 30 s HTTP timeout can abort mid-download.
> Export `UV_HTTP_TIMEOUT=600` for the first sync. 

```bash
git clone https://github.com/pollen-robotics/microduck_rl
cd microduck_rl

# train the walking policy (uses your GPU; ~1-2 h for a usable gait at 4096 envs)
uv run train Mjlab-Velocity-Flat-MicroDuck --env.scene.num-envs 4096

# watch a trained policy in the viewer
uv run play Mjlab-Velocity-Flat-MicroDuck --wandb-run-path <entity/project/run_id>

# export to ONNX for deployment
uv run scripts/export.py Mjlab-Velocity-Flat-MicroDuck --wandb-run-path <...>
uv run publish --onnx output.onnx --repo <user>/microduck-<name> --kind episodic --duration-s 4.0   # share it (see "Publishing a policy")

# drive the exported policy in CPU MuJoCo with the keyboard
uv run scripts/infer_policy.py --walking output.onnx
```

Resume from a checkpoint:

```bash
uv run train Mjlab-Velocity-Flat-MicroDuck --env.scene.num-envs 4096 \
    --agent.run-name resume --agent.load-checkpoint model_29999.pt --agent.resume True
```

No GPU? Add `--hf-jobs` to any train command to run it on Hugging Face Jobs
instead of locally (see [scripts/hf/README.md](scripts/hf/README.md)).

## Tasks

`uv run list-envs` prints the live registry. Flat/Rough variants exist where noted.

<!-- SHOWCASE GRID — one short GIF per task family (sim or real), 3 per row.
     Priority order if you only record a few: Velocity, VelStand (fall+recover),
     Roulade, SitStand, Rollers/Swizzle, BallKick. -->

| Task id | Terrain | Description |
|---|---|---|
| `Mjlab-Velocity-{Flat,Rough}-MicroDuck` | flat/rough | **The main task**: walking with velocity commands + head-pose commands |
| `Mjlab-VelStand-{Flat,Rough}-MicroDuck` | flat/rough | Walking + fall recovery in one policy |
| `Mjlab-StandUp-{Flat,Rough}-MicroDuck` | flat/rough | Stand up from face-down/face-up/sitting, then hold the stand + body-pose control |
| `Mjlab-SitStand-{Flat,Rough}-MicroDuck` | flat/rough | Commanded sit ↔ stand in one policy, gently, head commandable |
| `Mjlab-GroundPick-{Flat,Rough}-MicroDuck` | flat/rough | Crouch and touch the ground with the mouth tip, return to stand |
| `Mjlab-BallKick-Flat-MicroDuck` | flat | Kick a 70 mm / 15 g ball forward (actor is ball-blind) |
| `Mjlab-Roulade-Flat-MicroDuck` | flat | Forward roll over the head, land back on the feet |
| `Mjlab-Velocity-Flat-MicroDuck-Rollers` | flat | Roller-skate velocity tracking (passive wheels under the feet) |
| `Mjlab-Velocity-Swizzle-MicroDuck` | flat | Classic symmetric swizzle skating |
| `Mjlab-RollerCrouch-Flat-MicroDuck` | flat | Crouch while gliding on rollers |
| `Mjlab-RollerSlope-Flat-MicroDuck` | slope | Glide down slopes on rollers |
| `Mjlab-RollerStandUp-Flat-MicroDuck` | flat | Stand up from the ground onto the wheels |
| `Mjlab-Spin-Flat-MicroDuck` | flat | Fast spin in place on rollers |

At deployment the runtime hot-swaps these policies (walk / recover / trick)
behind a shared 61-dimensional observation contract, so any of them can take
over the robot at any moment. `scripts/infer_policy.py` rehearses exactly that:

```bash
uv run scripts/infer_policy.py --walking walk.onnx --standing stand.onnx \
    --sitstand sitstand.onnx --roulade roulade.onnx --new-cmd-obs
```

Keyboard-driven (velocity commands, `G` ground pick, `Y` sit/stand, `R` roulade,
`K`/`L` kicks); `--debug`, `--save-csv`, `--record` support sim2real comparisons.
The servos are simulated with the same BAM M6 XL330 model the policies are
trained against (voltage control + load-dependent friction, via
`bam.mujoco.MujocoController`); `--vin` / `--vin-drop-gain` / `--kp-fw` pin the
training DR ranges to one value, `--no-bam` falls back to the XML PD actuators.

### Backlash variants

Every main task has a **Backlash** twin that trains on a model with ±1° of gear
play (2° total) in series with each of the 14 servo joints: insert `-Backlash`
before `MicroDuck` in the task id, e.g. `Mjlab-Velocity-Flat-Backlash-MicroDuck`.

The backlash is modeled properly for sim2real: each servo gets an unactuated
`passive_<joint>_backlash` hinge, and because the real encoder sits on the
output side of the play, both the firmware PD emulation
(`BacklashEncoderBamActuator`) and the `joint_pos`/`joint_vel` observations
read *through* the backlash (`qpos[servo] + qpos[backlash]`). Observation and
action dims are unchanged, so ONNX export and the runtime need no changes.
See `src/mjlab_microduck/tasks/backlash.py`.

## Actuator model

All tasks use the [BAM](https://github.com/Rhoban/bam) M6 actuator model for
the Dynamixel XL330 (voltage control law, back-EMF, Coulomb/Stribeck/load-dependent
friction), with per-env domain randomization on battery voltage, voltage sag
under load, command delay, and friction magnitude
(`FrictionDRBamActuator` in `src/mjlab_microduck/actuator/`).

At this scale — tiny servos driving a ~800 g biped — actuator fidelity is most
of the sim2real gap, which is why the actuator is modeled down to its voltage
control law instead of an ideal PD.

## Robot models

MJCF models live in `src/mjlab_microduck/robot/microduck/` and are exported
from Onshape with [onshape-to-robot](https://github.com/Rhoban/onshape-to-robot),
one `config_mjcf_*.json` per model:

| XML | Used by |
|---|---|
| `robot_walk.xml` | Velocity (stripped trunk/head contacts — falling is cheap) |
| `robot_groundcontact.xml` | VelStand, StandUp, SitStand, GroundPick, BallKick, Roulade (curated collision set for the parts that touch the floor — body can physically lie on the ground; formerly `robot_allcollisions.xml`) |
| `robot_groundcontact_rollers.xml` | Roller tasks (passive wheels) |
| `robot_allcollisions.xml` | True full-collision model — every part has a collision geom. No task uses it yet |
| `robot_*_backlash.xml` | Backlash task variants (generated by `add_backlash.py`) |

`scene*.xml` files wrap the robots with a floor + keyframes (STAND/SIT/FOLD)
for quick viewing and for `infer_policy.py`.

<!-- IMAGE — side-by-side render: walk model vs rollers model (or a collision-geom
     visualization). One image here makes the model-variant story instant. -->

## Project structure

```
src/mjlab_microduck/
├── robot/
│   ├── microduck/                    # MJCF exports, export configs, scenes, add_backlash.py
│   └── microduck_constants.py        # robot cfgs, HOME frame, BAM actuator cfg
├── actuator/friction_dr_bam.py       # BAM + friction DR + backlash encoder feedback
├── tasks/
│   ├── __init__.py                   # task registration (base + backlash variants)
│   ├── mdp.py                        # rewards, events, observations, custom classes
│   ├── backlash.py                   # make_backlash_variant() env-cfg wrapper
│   └── microduck_*_env_cfg.py        # one cfg module per task family
├── train_cli.py                      # `train` script (identical to mjlab's)
├── train_hook.py                     # intercepts `train ... --hf-jobs`
└── hf_jobs.py                        # Hugging Face Jobs submission
```

Conventions worth knowing:

- The observation layout is shared across every policy (61-dim actor obs:
  48 proprioception + commands `[twist(3), head_pose(4), body_pose(6)]`), which
  is what makes runtime policy hot-swapping possible. Envs that don't use a
  command slot zero-pad it rather than dropping it.
- Unactuated joints are all named `passive_*` (roller wheels, backlash
  hinges); actuators, joint observations and pose rewards select servo joints
  with `^(?!passive_).*`.
- Domain-randomization toggles are `ENABLE_*` booleans at the top of each
  env cfg file.
- Joint layout (14 servos): 0–4 left leg (hip_yaw, hip_roll, hip_pitch, knee,
  ankle), 5–8 neck/head (neck_pitch, head_pitch, head_yaw, head_roll),
  9–13 right leg.
- The exporter bakes the observation normalizer into the ONNX graph — always
  deploy ONNX produced by `scripts/export.py`, never a hand-converted
  checkpoint, or the policy sees unnormalized observations at runtime.

[AGENTS.md](AGENTS.md) documents the env-building workflow and the reward-design
rules learned across the project (also aimed at AI coding agents working in
this repo).

## Publishing a policy

`uv run publish` puts a policy on the Hugging Face Hub in the shape the robot's
daemon loads: one `policy.onnx` with the observation normalizer baked in, a
`manifest.json` following schema 2 of the
[microduck policy manifest](https://github.com/pollen-robotics/microduck/blob/main/docs/policy-manifest.md),
and a README saying how to run it. Anyone with a microduck can then install it
with one command, no daemon release needed.

```bash
# From a wandb run — exports through the one safe path, then uploads
uv run publish --task Mjlab-PoliteBow-Flat-MicroDuck \
    --wandb-run-path <entity/project/run_id> --checkpoint 3000 \
    --repo <user>/microduck-polite-bow --kind episodic --duration-s 4.0 \
    --description "Bows from a two-foot stand and comes back up."

# From an ONNX you already exported (validated, not re-exported)
uv run publish --onnx output.onnx --repo <user>/microduck-flamingo \
    --kind perpetual --unwind-s 1.5 --twist-help "[flag, side, 0]"

# A new gait for a slot
uv run publish --onnx output.onnx --repo <user>/microduck-my-walk --kind perpetual --slot walk

# Ship a rollout video too: uploaded as replay.mp4, which the Hub's replay widget plays
uv run scripts/render_policy.py output.onnx --seconds 10 --video media/bow.mp4
uv run publish --onnx output.onnx --repo <user>/microduck-bow --kind episodic --duration-s 4.0 \
    --video media/bow.mp4

# A remix (warm-started / fine-tuned from someone's published policy): name the parent so the
# model card sets `base_model` and the Hub links the two
uv run publish --onnx output.onnx --repo <user>/microduck-deep-bow --kind episodic --duration-s 5.0 \
    --base-model <owner>/microduck-polite-bow

# See what would be uploaded without touching the Hub
uv run publish --onnx output.onnx --repo <user>/microduck-bow --kind episodic --duration-s 4.0 --dry-run
```

Then on a robot:

```bash
sudo robotctl policy add polite-bow <user>/microduck-polite-bow   # episodic: length comes from the manifest
sudo robotctl policy add flamingo <user>/microduck-flamingo --hold 5   # held pose: you pick how long
sudo robotctl policy load walk <user>/microduck-my-walk                # gait: into the walk slot
robotctl robot do polite-bow
```

What `--kind` means, and what each needs:

- **episodic** — runs for `--duration-s` and returns itself to a standing pose
  (kicks, roulade, a bow). Add `--chain` if holding the button should repeat it.
- **perpetual** — runs until told otherwise. Two shapes:
  - a **gait** (a new walk or stand): add `--slot walk` (or `stand`) and
    nothing else; the owner installs it with `robotctl policy load walk <repo>`.
  - a **held pose** (the flamingo): give `--unwind-s`, how long the daemon
    drives the idle twist (`--idle`, zeros by default) before handing back to
    the gait, so the robot is not let go of on one foot. The owner runs it as a
    one-shot with `policy add ... --hold <seconds>`.

Before anything is uploaded, `publish` checks the graph is `[1,61] -> [1,14]`
(a 51-D legacy policy is refused with a message), runs it on plausible inputs
and refuses NaNs or a constant output, fills the `training` block from git and
wandb (task, commit, branch, dirty flag, run, checkpoint), and refuses to
overwrite an existing `.onnx` in the repo without `--force`. Repos are created
private; `--no-private` for public, `--tag v1` to tag the revision.

Only constant-command policies are publishable this way. Phase-driven moves
(the ground pick) and the posture-flag sit↔stand are driven by the daemon
itself and live in the official set, `pollen-robotics/microduck-policies`.

## Tests

```bash
uv run --with pytest pytest tests/
```

CPU-only config-invariant and reward-function regression tests — they lock in
joint-index mappings, reward sign conventions, and NaN guards.

## Related projects

- [microduck](https://github.com/pollen-robotics/microduck) — the Microduck project home, including the onboard runtime that runs the exported policies
- [mjlab](https://github.com/mujocolab/mjlab) — the training framework (MuJoCo Warp + rsl_rl)
- [BAM](https://github.com/Rhoban/bam) — better actuator models, by Rhoban

## License

This project is licensed under the Apache 2.0 License. See the [LICENSE](LICENSE) file for details.
3D model files are licensed under Creative Commons BY-SA-NC.

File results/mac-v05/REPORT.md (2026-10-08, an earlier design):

# V05 mounted MicroDuck: Mac simulation pilot

**Local simulation and training work. The current mount is not ready for a reliable walking policy.**

The model weighs 0.737 kg stock and 1.189 kg loaded: **451 g added, a 61% increase**. Payload mass includes the Jetson, GNB 850 mAh pack, fully dense printed mount, and ancillary wiring/hardware allowances. The earlier static calculation puts the loaded center of mass about 12 mm farther back.

## Existing walking policy

Same official `alpha_walking.onnx`, paired seeds 0–7, ten-second trials, no assistance. Forward command is 0.30 m/s; stationary command is zero. Motor voltage/sag draws and initial-pose draws are matched by constructing each robot with the same seed. Separate pristine models prevent one trial's motor state affecting another.

| Measure | Stock | Loaded |
|---|---:|---:|
| Forward trials without a fall | 8/8 | 8/8 |
| Mean forward displacement in 10 s | 1.095 m | 0.232 m |
| Effective world-forward speed | 0.109 m/s | 0.023 m/s |
| Stationary trials without a fall | 8/8 | 7/8 |
| Mean world-forward displacement at stationary command | +0.002 m | −0.573 m |

The loaded robot can move but has pronounced backward drift at zero command. Forward displacement is projected onto the starting world-forward axis; it is not total path length. These short nominal-physics trials are not a reliability estimate for hardware.

The mount's upper gate bridge contacts the head-shell collision meshes during motion. MuJoCo uses convex robot meshes and conservative mount boxes, so this flags a clearance problem requiring exact CAD inspection; it does not establish an exact physical penetration. No collision geometry was disabled to improve the result.

[Mounted forward video](preview-loaded-forward.mp4) · [stationary-command video](preview-loaded-stand.mp4) · [raw paired results](baseline.json).

## CPU training

Eight parallel environments per variant, same seed 0, 1,048,576 PPO transitions each, BAM motors, no assistance or mirror loss. Stock completed in 95 seconds; loaded in 125 seconds, including startup/export. Normalization is baked into the exported ONNX policies. This is one training seed and a small sample budget.

The stock pilot learned to stand rather than walk. The loaded pilot collapsed onto its backpack: under the original height/tilt fall thresholds it appeared to survive all standing trials, despite using non-foot floor support in about 94% of steps. It fell in 7/8 forward trials. **Both pilot policies are rejected.**

A strict floor-support guard now rejects all 8/8 of the loaded pilot's standing, forward, and turning trials. The guard preserves the 61/14 interface, reward terms, and motor physics. A stock teacher rollout passes it; the backpack-supported pilot fails it. Both guarded trainers also completed a 16,384-step smoke run.

[Rejected training-policy video](trained-preview-loaded-stand.mp4) · [training summary](training_summary.json) · [strict evaluation](trained-loaded-strict.json) · [experimental checkpoints](policies/).

## Verification and next work

Masses, positive inertias, 14 actuators, 61 observations, policy timing, exact repeatability of isolated seed-0 rollouts, and the floor-support guard passed [verification](verification.json). Rendered contact sheets were inspected alongside the metrics. Setup was re-run successfully; an archived native checkpoint resumed for 2,048 guarded PPO steps and exported successfully. Fixed-pose servo targets without the walking policy fall in roughly 1.38 s stock / 0.64 s loaded, so the policy supplies essential stabilization.

Reduce the rearward payload moment, clear the moving head and limbs, then distill/fine-tune a competent walking policy with the stricter fall check. Longer runs should include payload uncertainty, observation noise, servo supply/sag variation, delays, pushes, and hardware parameter checks. Print flex, attachment slip, cable dynamics, thermal behavior, and battery runtime are outside this rigid-body pilot.

Early exploratory outputs without a construction seed were superseded by the reproducible paired results above; BAM samples supply parameters at construction, and resetting the episode seed alone does not fix those draws. Failed or backpack-supported policies were not labeled as walking successes.

[Mac setup and reproduction](../../training/README.md).

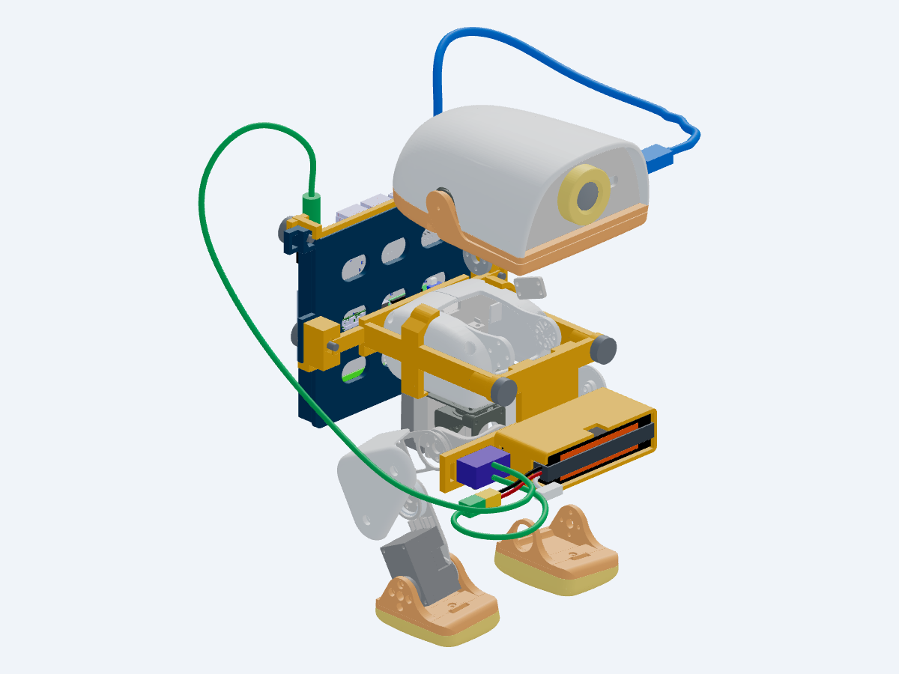
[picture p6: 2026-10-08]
docs/v05-robot-front.png

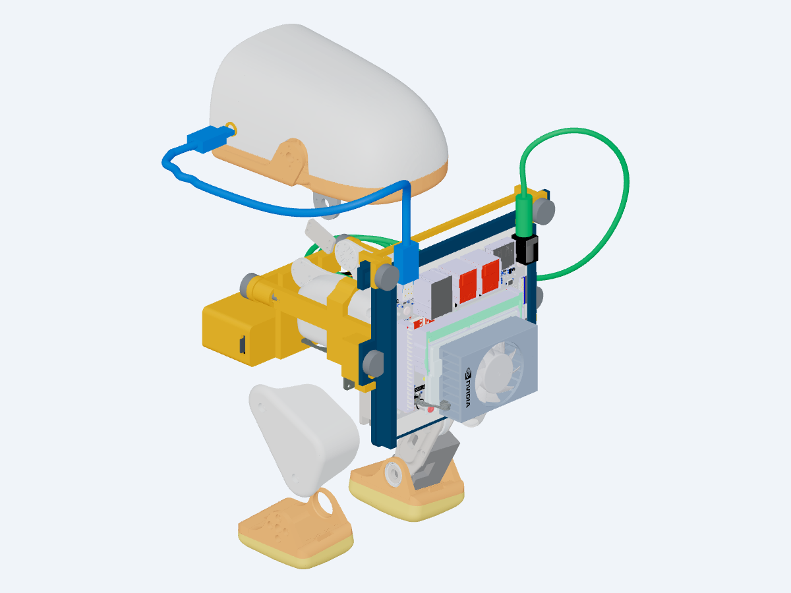
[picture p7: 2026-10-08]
docs/v05-robot-rear.png

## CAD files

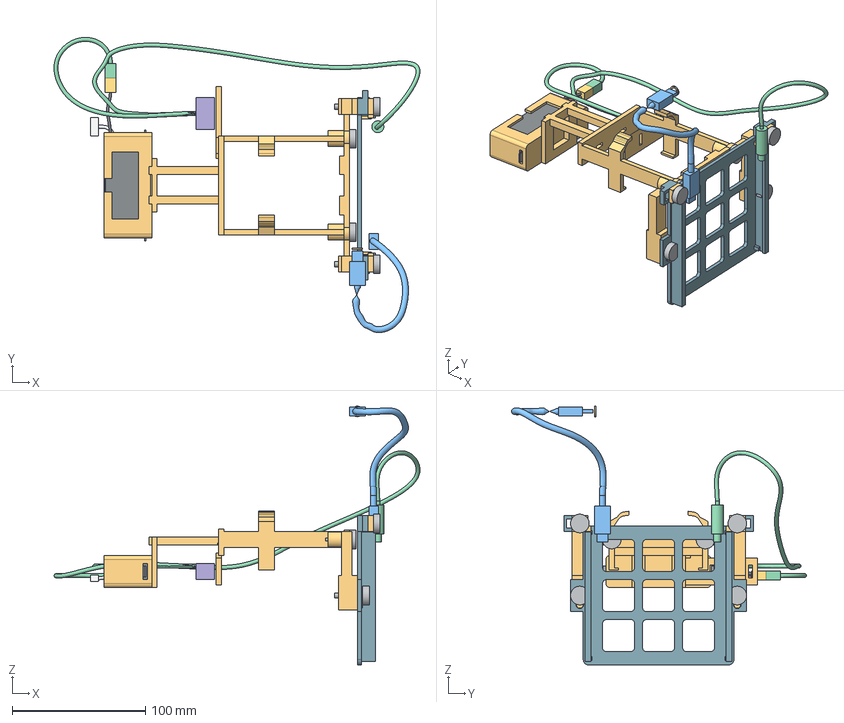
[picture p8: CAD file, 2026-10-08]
easy_mount/STEP/easy_mount_assembly.step
274.3 x 221.2 x 194.0 mm
part_o1.1.1
part_o1.1.2
part_o1.1.3
part_o1.1.4
part_o1.1.5
part_o1.1.6
part_o1.2.1
part_o1.2.2
part_o1.2.3
part_o1.2.4
part_o1.2.5
part_o1.2.6
unselected_regulator_fit_allowance
UNVERIFIED_head_access_survey_marker_NOT_A_PORT
GNB8504S60AHV_73x18x32mm_73g_spec_envelope
GNB_4S_850mAh_label_illustration
nonconductive_bottom_pad_0_6mm
purchased_retaining_strap_illustrative
approx_factory_discharge_lead x 2
XT30_factory_plug_approximate
approx_factory_balance_bundle
JST_XH_5pin_approximate_verify_pack
saddle
front_gate
jetson_tray
jetson_gate_left
jetson_gate_right
M4x20_torso_thumb_screw x 2
M4x20_tray_thumb_screw x 2
M4x12_Jetson_gate_thumb_screw x 2

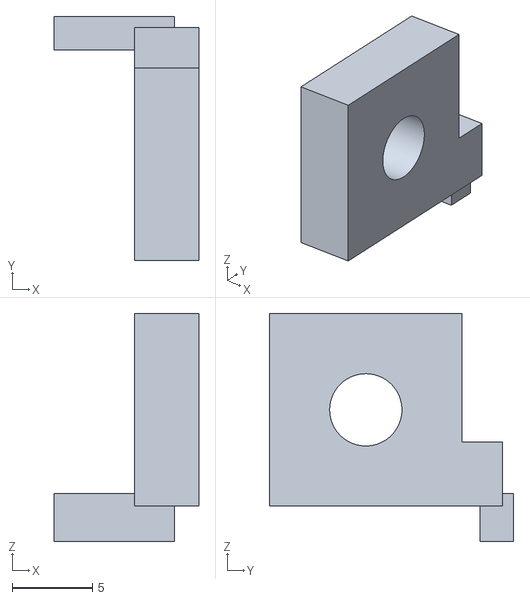
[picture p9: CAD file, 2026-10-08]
easy_mount/simulation/meshes/jetson_gate_left.stl
9.00 x 15.2 x 14.2

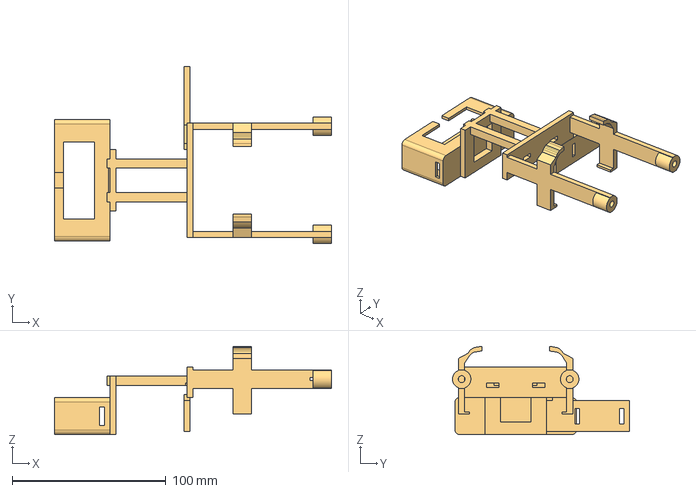
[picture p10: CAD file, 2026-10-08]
easy_mount/STEP/saddle.step
180.0 x 115.1 x 57.2 mm

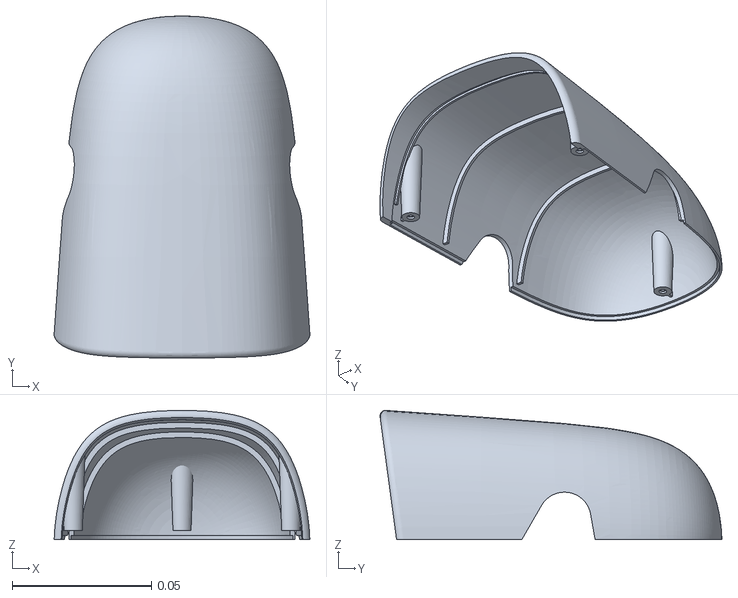
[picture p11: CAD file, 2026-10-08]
simulation/reference/assets/top_head_shell.stl
0.0918 x 0.123 x 0.0463

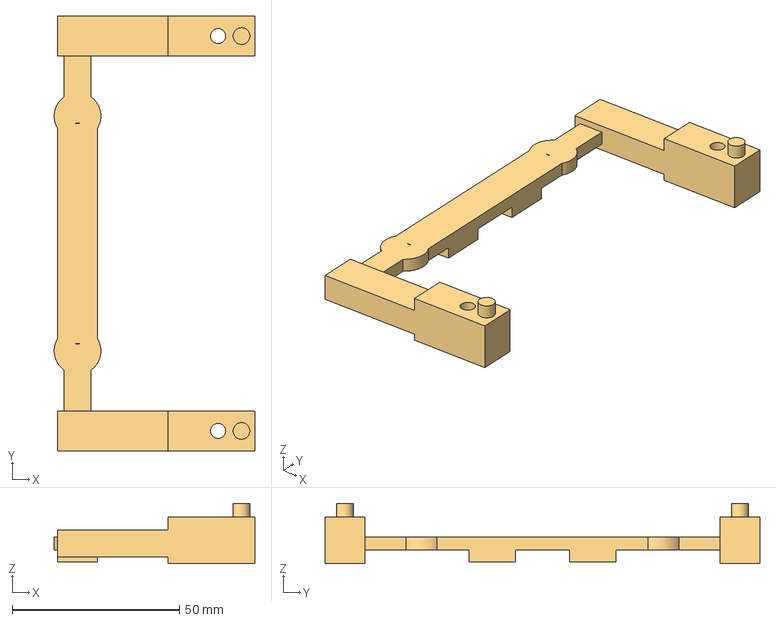
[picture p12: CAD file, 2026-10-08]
easy_mount/STEP/front_gate.step
60.0 x 130.0 x 18.0 mm

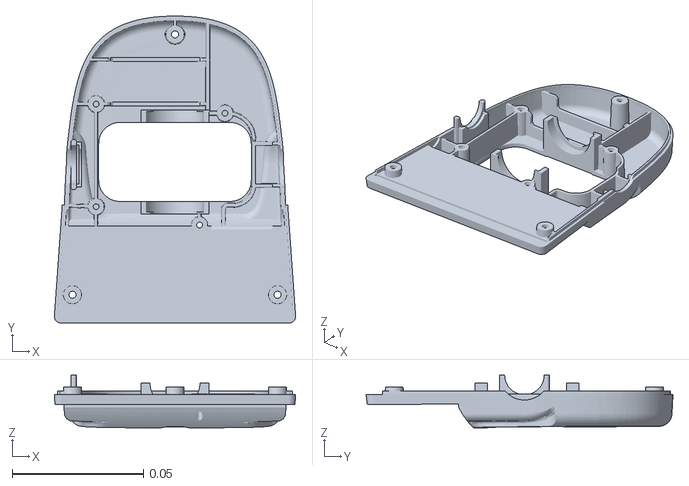
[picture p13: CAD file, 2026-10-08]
simulation/reference/assets/bottom_head_shell.stl
0.0918 x 0.117 x 0.0201

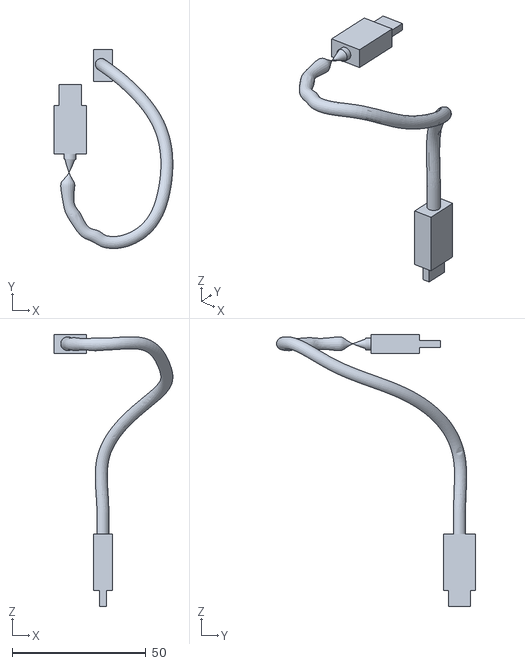
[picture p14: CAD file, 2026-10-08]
easy_mount/simulation/meshes/wiring_data.stl
44.3 x 74.3 x 101.5

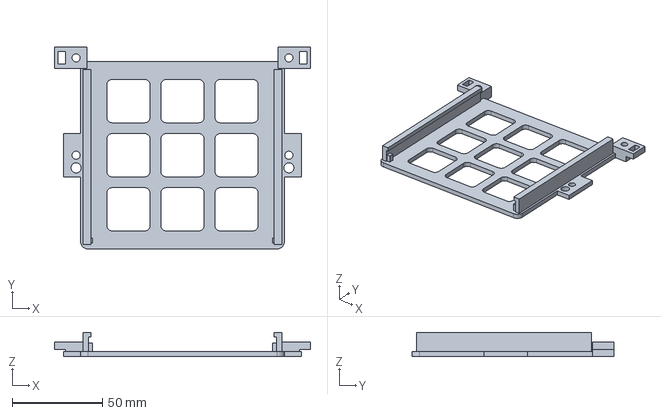
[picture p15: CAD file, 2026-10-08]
easy_mount/STEP/jetson_tray.step
142.0 x 112.0 x 13.5 mm

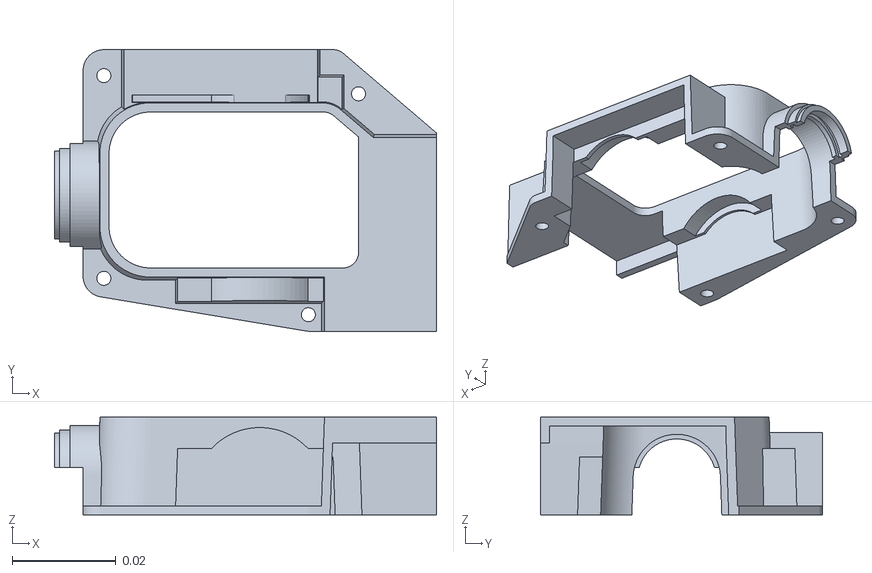
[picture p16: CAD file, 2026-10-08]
simulation/reference/assets/motor_support.stl
0.0735 x 0.0542 x 0.0188

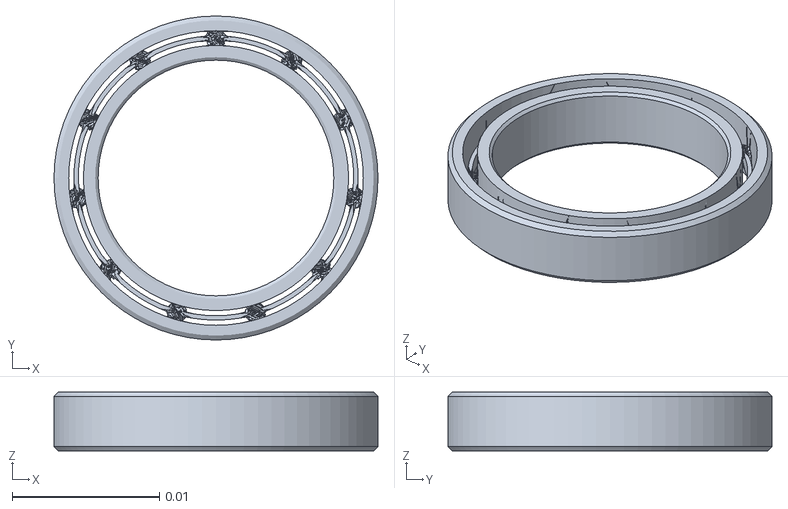
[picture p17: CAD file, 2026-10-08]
simulation/reference/assets/seeed_bearing__configuration__22x16x4.stl
0.022 x 0.022 x 0.004

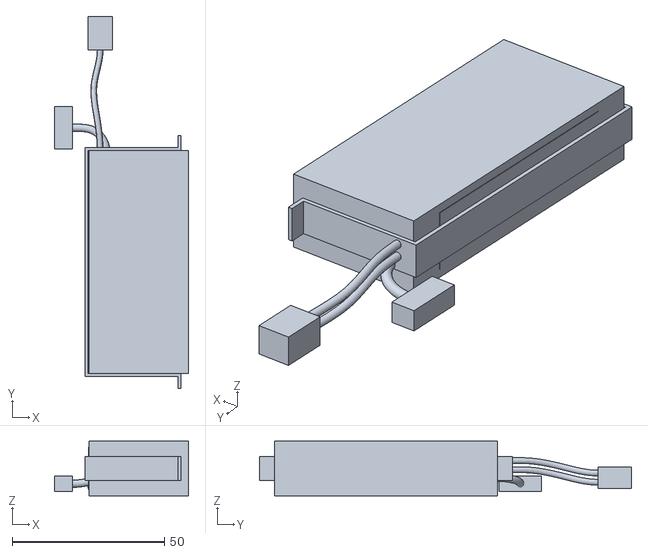
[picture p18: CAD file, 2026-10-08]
easy_mount/simulation/meshes/battery_pack.stl
44.0 x 122.0 x 18.0

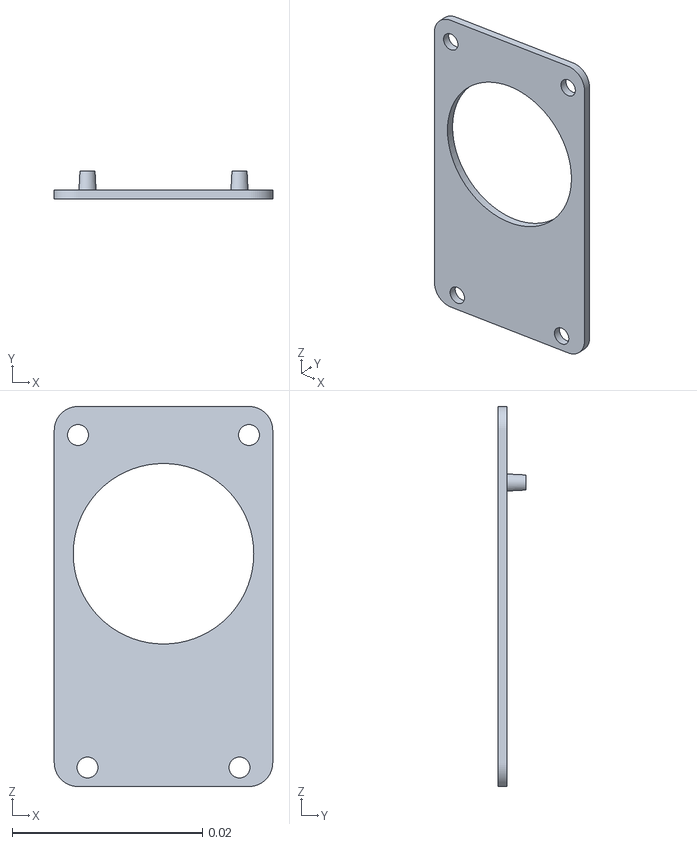
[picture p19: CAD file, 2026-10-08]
simulation/reference/assets/bearing_roll.stl
0.023 x 0.003 x 0.04

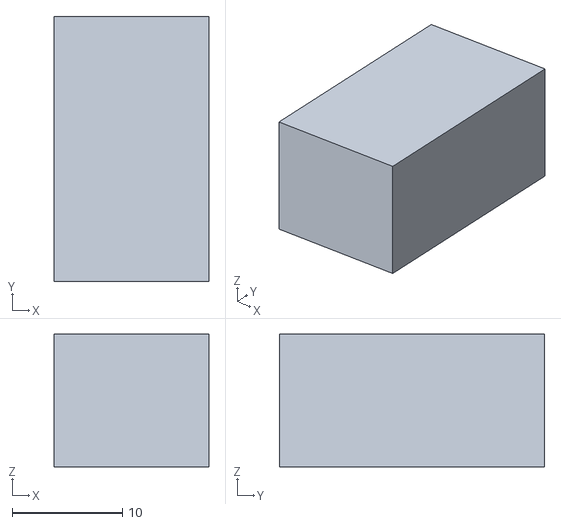
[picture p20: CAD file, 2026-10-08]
easy_mount/simulation/meshes/wiring_converter.stl
14.0 x 24.0 x 12.0

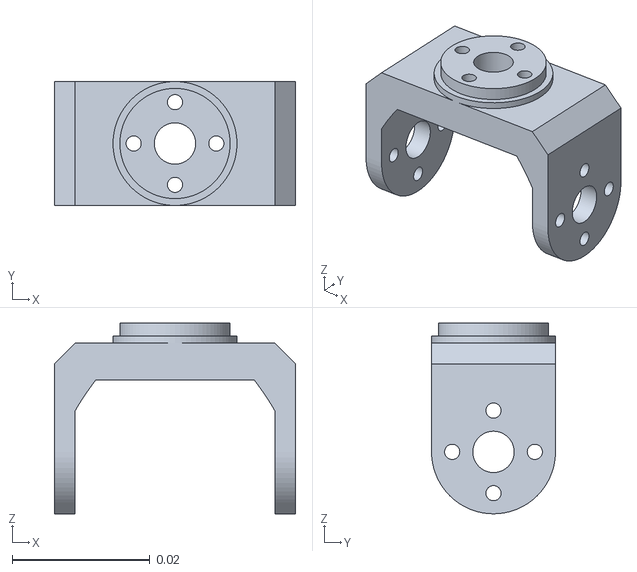
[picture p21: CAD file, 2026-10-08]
simulation/reference/assets/neck_pitch.stl
0.035 x 0.018 x 0.0277

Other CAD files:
easy_mount/simulation/meshes/jetson_gate_right.stl
easy_mount/simulation/meshes/front_gate.stl
easy_mount/STEP/jetson_gate_right.step
easy_mount/STEP/jetson_gate_left.step
easy_mount/STEP/battery_pack.step
easy_mount/STEP/imported/iso4032_hex_nut_m4.step
easy_mount/STEP/wiring_layout.step
easy_mount/STL/front_gate.stl
easy_mount/STL/jetson_gate_left.stl
easy_mount/STL/jetson_gate_right.stl
easy_mount/STL/jetson_tray.stl
easy_mount/STL/saddle.stl
easy_mount/simulation/meshes/jetson_tray.stl
easy_mount/simulation/meshes/saddle.stl
easy_mount/simulation/meshes/wiring_power.stl
simulation/reference/assets/ankle_left.stl
simulation/reference/assets/ankle_right.stl
simulation/reference/assets/banana_pcb_locker.stl
simulation/reference/assets/elec_rpi_robot_hat_pcb.stl
simulation/reference/assets/face_part.stl
simulation/reference/assets/foot_left.stl
simulation/reference/assets/foot_right.stl
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

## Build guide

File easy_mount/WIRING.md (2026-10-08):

# Wiring fit study — v06

Blue: USB-C data cable from Jetson J5 to a **FREE head-side plug**. The amber
ring marks an area to survey, not a modeled socket, opening or drilling target.
Green: custom XT30 extension → purple conditioning/protection allowance → Jetson J16 barrel plug. The GNB8504S60AHV pack has an XT30 discharge plug; approximate red/black factory leads and a balance connector are now shown. No conditioning or low-voltage protection circuit is selected.

## Which ports exist?

The current MicroDuck software identifies its computer as a Radxa ZERO 3W.
Radxa documents two USB-C connectors: USB-C 1 is power/USB 2.0 OTG; USB-C 2 is
USB 3.0 HOST. The proposed data link uses the **host port**, with a data-capable
USB-C-to-USB-C cable, into Jetson J5 in USB device networking mode. NVIDIA
supports virtual Ethernet on this connector. The Jetson still requires separate
DC barrel power; its USB-C connector does not power the developer kit.

This confirms board capability, **not access through the duck's enclosure**.
The pinned public simulation model puts two compute-board meshes in the head,
and one is explicitly an older Raspberry Pi Zero 2 W footprint. It does not
model the production Radxa USB sockets. Consequently this revision does not
invent an exterior port or drill/cut the stock shell. The head-side plug is
parked outside the reference shell, visibly disconnected.

Measure the actual board orientation, free host socket, shell openings and
available plug clearance before finalizing this end. Access may require opening
the head once and fitting a short extension through a verified cable exit.
Keep the robot's existing motor controller and power wiring intact. Transporting
policy observations/actions also requires the software bridge discussed earlier;
a cable alone does not add that feature.

## Geometric assumptions

- Jetson rotates 180° **in its tray plane**; USB, Ethernet and DC connector edge
  now faces upward. Its existing plastic base stays attached.
- J5/J16 connector centers come from NVIDIA's P3766/P3768/P3767 vendor STEP
  centroid annotations. Connector face planes are estimated from the vendor
  envelope, and the modeled plug bodies are generic overmold allowances.
- Approximate USB plug bodies: 12×21×7 mm at Jetson, 12×18×7 mm at the free
  head end. Cable diameter 4.5 mm. Main blue centerline is about 162 mm.
- Approximate DC plug body: 9 mm diameter ×22 mm. Power cable diameter 3 mm.
  Main power centerline is about 450 mm, plus a custom XT30 extension. Exact spline lengths are in `simulation/validation.json`.
- Curved service loops target at least 10 mm bend radius. These are sampled
  geometric radii, not cable-manufacturer approvals or a head travel test.
- Two outboard tray eyes accept cable ties for strain relief. Leave head-side
  slack free to move. Do not tie it across a joint or tension a board socket.
- Converter allowance 14×24×12 mm, strapped to the rear saddle side pad;
  its electrical suitability is completely unverified. Replace its dimensions
  and mass with the selected converter before printing that pad.

Catalog search: step.parts queries `USB-C` and `USB C cable` returned sockets,
USB-C-to-micro-B, magnetic, panel-mount and micro-USB parts, but no matching
USB-C-to-USB-C cable. These simplified envelopes are labeled as such.

## Simulation and validation

The 74 g ancillary budget comprises hardware/pads/straps 22 g, USB cable 14 g,
power wiring 18 g (including the custom XT30 extension) and converter 20 g. Wiring mass and inertia use their modeled
HOME locations, with no duplicate ancillary lump. Cable visual meshes have zero
mass; stock battery leads/connectors are included in its specified 73 g and approximated at the body COM. The payload's explicit inertial contains all mass once. Cables are fixed
visuals in this approximation, without flexible tension, moving-head mass
redistribution or rigid cable collision forces.

`simulation/validation.json` records native cable/print intersection tests,
sampled spline lengths/radii and local capsule-to-robot distances in HOME.
It also records the hard mount's individual-joint sweeps. Full joint travel is
not cleared. No combination-motion, insertion, durability or live electrical
test has been performed.

## Primary references

- [Radxa ZERO 3 hardware interfaces](https://docs.radxa.com/en/zero/zero3/hardware-design/hardware-interface)
- [NVIDIA Orin Nano developer kit hardware layout](https://docs.nvidia.com/jetson/orin-nano-devkit/user-guide/hardware_layout.html)
- [MicroDuck robotd design](https://github.com/pollen-robotics/microduck/blob/main/docs/design/robotd-design.md)
- Pinned robot and NVIDIA CAD provenance: parent `simulation/reference/provenance.json`
  and `STEP/imported/provenance.json`.

Battery source, power assumptions and runtime estimate: `battery_selection.json` and `README.md`. Factory lead lengths, XT30 and balance plug shapes are approximate fit envelopes.

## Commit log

2026-10-08 Add MicroDuck Jetson mount v05 CAD, print files and simulation
    [ankle_left.stl, ankle_right.stl, banana_pcb_locker.stl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]
2026-10-08 Rebalance v06 Jetson mount and validate Mac walking comparisons
    [battery_pack.step, battery_pack.stl, easy_mount_assembly.step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]
2026-10-10 Train and validate faster mounted walking with bounded feedback
2026-10-10 Add calibrated directional motion policy, Mac controls and simulation video
2026-10-10 Improve mounted slow motion, stopping and push recovery with Mac validation
2026-10-11 Add mounted sit/stand diagnostics and trained front-recovery candidate
2026-10-11 Revise mount for seated clearance and validate v07 posture and walking policies
2026-10-11 Train and validate mounted walking on uneven terrain
2026-10-12 Train and benchmark mounted slope precision and push/trip/slip recovery
2026-10-12 Add local voice commands and combined mounted walking sit-stand controller
